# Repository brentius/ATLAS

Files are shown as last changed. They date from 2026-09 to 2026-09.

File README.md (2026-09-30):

# ATLAS
*Written in the prophetic perfect tense to give myself some motivation*

ATLAS (Atomic-scale Tunneling and Local Analysis Syste*) is a low-cost scanning tunneling microscope (STM) build inspired by Dimsmary's OpenSTM project (https://github.com/Dimsmary/OpenSTM), with the end goal to accurately image carbon atoms on the lattice of a sample of HOPG.

## File Structure

```
pcb/
code/
cad/
sim/
README.md
LICENSE-HARDWARE
LICENSE-SOFTWARE
.gitignore
```
## Licenses

Hardware design files in `pcb/` and `cad/`, including schematics, PCB layouts,
footprints, and mechanical designs, are licensed under the
[CERN Open Hardware Licence Version 2 – Strongly Reciprocal](LICENSE-HARDWARE)
(`CERN-OHL-S-2.0`). Hardware circuit netlists in `sim/` are covered by the same
license.

Software in `code/` and simulation scripts in `sim/` are licensed under the
[GNU General Public License Version 3](LICENSE-SOFTWARE) (`GPL-3.0-only`).

## How does ATLAS work?
ATLAS is a **scanning tunneling microscope** (STM). Essentially, you have a tip of some hard conductive material (Pt-Ir in this case) that is brought within nanometers of a sample, and very slowly moved along it. As the tip moves along the sample, electrons can tunnel from the atoms in the sample to the tip, which creates a miniscule current. What an STM does is take that current and through PCB wizardry amplify it into something readable, and from that construct a 3D image of the sample at the atomic scale.
# The project itself...
## A bit about this project
*For a more detailed log, refer to my blog at brentius.github.io/blog.*

I first started thinking of this project after my GCSEs in late June 2026, but I really didn't start work until September/October of that year. I'd been (very slowly) working my way through Griffths's *Introduction to Quantum Mechanics* the year before, and I thought it'd be a great idea to simply have fun and play around with quantum tunneling for a bit. I also wanted to do an actual *practical* project, because I absolutely adore PCB design - it's almost theraputic (triggers the same bits of my brain as those iPad games where you need to connect the dots without the lines crossing each other). But before I started any work, the project had to satisfy a few criteria:

1. Is it cool or not? Self explanatory, and I think I made the right choice.
2. Will it kill me? No matter how cool a project, there's not much use in doing it if I die in the process; I'd quite like to stay alive, thank you very much.
3. What can I learn from it? I've always been itching to try my hand at FPGAs, and this project was the perfect opportunity to do so.
4. How expensive will it be? At the end of the day, I don't have infinite funding; if I fry a PCB, or I break a Pt-Ir tip, it's coming out of my own pocket. Not ideal.

The only project that really satisfied all 4 criteria was building an STM, so I got to work on it. I was on vacation in Spain and Sweden during July, so there really wasn't much I could do except for starting to work on the PCBs. And my god, were these a pain.

ATLAS consists of 3 PCBs:
1. **TIA/preamp**. This uses an OPA828 DAC, along with a 100M resistor, to take in the *absolutely miniscule* current from electrons tunneling from the sample to the tip and amplify it by ~10e8 V/A, to get 15 volts running out of the back. This was actually one of the easier PCBs to design, mostly because of how few components there were. The main difficulty in designing the TIA board was physical routing - the current input trace had to be as short as possible and use as little copper as possible, and it also needed to be fenced off with the Great Wall of Vias (there's probably a Latin joke to be made in there but frankly I'm too dumb to make it) to protect it from interference from other traces. This meant that the shape of the board itself was hard to design, as the resistor meant that the board was quite large in both X and Y; considering this had to sit on the scanner block, it was not ideal.
2. **Converter/Pmod carrier**. This was about the point where I figured out I was probably extremely out of my depth. The Converter acts as a translator between the FPGA and the analog circuitry; onboard there's a SAR ADC, which takes the output from the TIA and digitises it for a PID loop. There are also two DAC8734s, that generate the X/Y/Z scan and feedback drive voltages (10 volts). Meanwhile, the AD7521 IC handles the DAC for the stick-slip sliding mechanism. Pmod headers carry SPI and control lines to and from the FPGA. As you can probably tell, this board was an absolute nightmare to design, and is the cause of many sleepless nights I will not get back.
3. **PSU**. All good things need power, and ATLAS is no exception. It runs on 15V - my original design called for a 45V rail to drive the tip movement for maximum range, but I decided against it for redundancy's sake - this project is already complicated enough without splitting 3 power rails (10, 15 and 45V).
### Damping
The PCBs were only one part of the challenge. A STM is an extremely sensitive instrument - after all, it's imaging individual atoms - even someone shouting next to it *will* throw the measurement off. To that end, ATLAS was built in one of the less used classrooms of Winchester College Mill, to keep foot traffic to a minimum; and a large sign was taped to the door telling people to keep their voices down. BUT THAT WASN'T ENOUGH! Any vibrations of the table would also throw the tip off by millimeters (matters a lot on the nanometer scale), so the whole system had to be on a damper.

The initial damper concept uses a frame, 8 springs and a 12lb slab of granite supporting the scanner assembly. The slab weight is adjustable rather than a fixed design requirement. No spring-rate or frequency measurement is recorded here, so the earlier 1Hz estimate is unverified. The [suspension calculation](sim/atlas_mechanics/SUSPENSION_BUDGET.md) and [comparison with other STM isolation designs](sim/atlas_mechanics/ISOLATION_OPTIONS.md) set out a modular trial of the spring stage, optional magnetic eddy-current damping and a short plate stack. Wind, sound and cable disturbances still need physical testing. I briefly considered building an enclosure with ANC, but I ultimately decided against it - the last thing I need is another signal processing challenge. It would be fun though...
## Assembly
*The instructions provided below are but a summary, and your version of ATLAS will probably not work if you just follow these. For a more detailed set of instructions, or if you'd like to see how I did it, please refer to brentius.github.io/blog.*

A full bill of materials can be found at ```BOM.md```.
### Part I. The Scanner Block
This is the scanner block - i.e. the block that actually does the scanning. One of the main insights I lifted from OpenSTM was to use a buzzer and a stick-slip mechanism to slowly increment the position of the tip, which franly I think was an insight of genius. Why a buzzer? While your typical linear actuators and belt drives work for 3D printing or CNC milling, an STM requires nanometer precision, which you physically can't achieve with a linear actuator. There's also the problem that linear actuators produce heat, which at nanometer scales, really throws the position off due to the joints expanding/contracting. We first quarter the 
#### Preparing the tip
Version 1 of ATLAS used a length of 80:20 Pt-Ir (platinum-iridium) wire that I simply cut at 45 degrees with a pair of sharp cutters. Boring, but it works.
# Meta Stuff
## Acknowledgements
# References

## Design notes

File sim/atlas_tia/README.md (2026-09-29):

# ATLAS TIA simulation

LTspice is suitable for the TIA compensation study. The `tia_opa828_*.cir`
files use TI's OPAx828 PSpice model. The `tia_proxy_*.cir` files are earlier
preliminary circuit checks using a deliberately simple 45 MHz gain-bandwidth
proxy. Open a `.cir` file in LTspice and click Run (or use LTspice batch mode).
For a `.cir` file, the working batch form is `LTspice.exe -b file.cir`.

## First TI-model run, 24 September 2026

LTspice 26.1.1 completed both TI-model netlists with exit code 0 and no logged
model errors. Baseline assumptions were 15 pF **external** input capacitance,
0.1 pF feedback stray capacitance, 100 pF output cable capacitance, and a
100 kΩ receiver. The 1 pA AC source gave about 99.8 MΩ low-frequency output
transimpedance. The 1 nA positive current step gave approximately -99.8 mV
output change (measured during the pulse, before it switched off).

| Fitted C1 | Simulated -3 dB bandwidth |
|---:|---:|
| 0.2 pF | 5.37 kHz |
| 0.5 pF | 2.66 kHz |
| 1 pF | 1.45 kHz |
| 5 pF | 0.312 kHz |

In this baseline, the maximum output magnitude from 1 Hz to 100 kHz occurred
at 1 Hz for all four values, so no gain peaking appeared in that interval.
The full 640-case parasitic/load and loop-gain sweep, tolerance corners,
step checks and evaluation are recorded in
[`COMPENSATION_STUDY.md`](COMPENSATION_STUDY.md).
The raw waveform and log files are local generated outputs and are ignored
by Git.

## Circuit represented

- 100 MΩ feedback resistor, stepped fitted C1 = 0.2, 0.5, 1, or 5 pF.
- Independent feedback stray capacitance, initially 0.1 pF.
- The proxy netlists add 15 pF for amplifier input capacitance. The TI-model
  netlists use the model's own input impedance and add only separately
  adjustable tip/PCB/cable capacitance.
- ±15 V incoming rails, 10 Ω series rail filters, 100 nF and 10 µF local
  capacitors on each rail.
- 220 Ω output resistor, provisional 100 kΩ receiver and output cable
  capacitance.

The AC files inject 1 pA AC into the tip. The transimpedance trace is
`-V(out)/1p`; nominal low-frequency magnitude is about 100 MΩ. Compare the
frequency response and peaking between C1 values. The step files apply
a 1 nA current step; the ideal settled output change is about -100 mV. The
proxy has only a single dominant pole and approximate output swing. It omits
the real amplifier's bias, noise, extra poles, overload behavior, and slew
limits. Consequently it cannot establish the planned 60° phase-margin gate.

## Remaining qualification

The 640-case AC and loop-gain sweeps are complete with the TI model. The
exact C1 part/tolerance, actual feedback stray capacitance, real cable and
receiver, supply impedance, noise, overload recovery and physical-board tests
remain open. The evaluation report states the population recommendation and
its limits.

The official TI archive `sbomaj0d.zip` and extracted `OPAx828.LIB` are in the
local `vendor/` directory, which is ignored by Git because the model is TI's
copyrighted evaluation material. The archive was downloaded from the OPA828
product page on 24 September 2026. Its top-level declaration is
`.SUBCKT OPAx828 IN+ IN- VCC VEE OUT`; the TI netlists connect `0 TIP VP VN RAW`
in that exact order. The model's usage notes list differential and common-mode
input impedance among the modeled parameters, so the TI netlists add only
external input capacitance. Model-specific results still require checking the
LTspice log and the physical board.

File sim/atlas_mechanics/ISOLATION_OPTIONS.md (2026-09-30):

# ATLAS isolation architecture comparison — 30 September 2026

## Recommendation for the next prototype

Use the existing spring-frame concept as a **modular test platform**, with
the total suspended mass adjustable. Compare (A) the bare suspended stage,
(B) the same stage with a conductive plate moving past frame-fixed magnets
for non-contact eddy-current damping, and (C) a short, two- or three-plate
metal/elastomer stack on the stage if the first two configurations leave
high-frequency coupling. This is a test sequence, **not** a selected slab
weight, spring, magnet gap or fabrication release. Keep the scanner, sample
and preamplifier on the same compact upper assembly; do not split the
tip/sample mechanical loop across stages. Fit, magnetic compatibility and
performance must be checked before adding a damper near the instrument.

Do not substitute passive permanent-magnet levitation for the springs at
this stage. The cited STM examples use magnets for **eddy-current damping**
of a mechanically supported mass, not as the vertical support. Static
permanent-magnet support of an ordinary ferromagnetic stage is not stable
in all directions without additional constraints or active control; a
levitation system would also introduce a new control/fault path. This is
an engineering recommendation based on the sources below, not a measured
comparison on ATLAS.

## Evidence from other STM builds

| Source and implementation | What it establishes | Limit for ATLAS |
|---|---|---|
| [OpenSTM build paper, section 5.1](https://arxiv.org/pdf/2310.05413) | Its reported build suspended a 10 kg stone from four springs, each listed at 408 N/m, and placed three 20 × 20 × 1 cm aluminium plates separated by fluoro-rubber rings on it. The paper says other isolation methods can be used. | It does not measure ATLAS's spring rate, mode frequencies or vibration transfer. Its four-spring value cannot be copied into an eight-spring design without recalculation. |
| [Dan Berard's build account](https://dberard.com/home-built-stm/vibration-isolation/) | Three long springs support an aluminium/MDF stage with a three-steel-plate Viton stack; fixed magnets near the moving aluminium plate provide eddy-current damping. The builder reports about 1 Hz **horizontal pendulum** and 2 Hz **vertical spring** resonances and uses fine 40 AWG wiring. | His 1 Hz number is not a vertical-spring specification and his site does not provide an ATLAS transfer measurement. |
| [J. Herkenhoff's STM repository](https://github.com/jherkenhoff/STM) | Uses steel plates separated by Viton pieces and describes optional spring/elastic-rope suspension and aluminium-base eddy-current damping. | Build description, not an ATLAS head/fixture qualification. |
| [Le's STM isolation thesis](https://digitalcommons.calpoly.edu/theses/2272/) | Develops a six-spring suspended copper stage with neodymium-magnet eddy-current damping and Viton at contacts. | Different geometry and environment; magnet position and damping remain to be engineered for ATLAS. |
| [Schmid and Varga, *Ultramicroscopy* (1992)](https://www.sciencedirect.com/science/article/pii/0304399192904934) | Their analysis finds spring/eddy-current and elastomer plate stages complementary. It also notes plate stacks can amplify some 10–100 Hz vibration and suggests only a few plates. | Do not add a plate stack on the assumption that more layers always improve isolation; compare transfer measurements. |
| [University of Virginia magnetic-levitation note](https://galileo.phys.virginia.edu/classes/317.gbh.fall05/mag-lev/mag-lev.html) | Explains why ordinary static permanent-magnet levitation is unstable without special materials or feedback. | Does not rule out every magnetic bearing, but does not justify a passive levitated ATLAS stage. |

The build accounts report their own configurations. They are not controlled
A/B measurements on one STM. In particular, OpenSTM's HOPG imaging is
evidence for its whole build, not proof that one isolation element alone
would outperform another element on ATLAS.

| ATLAS option | Main advantage | Main unresolved cost or failure mode | Trial role |
|---|---|---|---|
| Spring-supported mass alone | Reuses the present frame; mass and stiffness can be measured directly | Resonant amplification and cable bypass | Baseline first |
| Springs plus eddy-current plate/magnets | Adds adjustable non-contact damping without magnetic support | Magnetic interaction, extra moving mass and gap/clearance control | Reversible second configuration |
| Short metal/elastomer plate stack | Additional high-frequency attenuation may be possible | Creep, load/temperature dependence and possible 10–100 Hz amplification | Compare only if baseline/damper data justify it |
| Passive permanent-magnet levitation | Could remove a direct mechanical support path in a specialized design | Ordinary static magnets do not give stable unconstrained support; requires a different architecture | Not selected |
| Actively stabilized magnetic stage | Stability can be controlled in principle | Sensors, actuator power, control noise and fault behavior become part of the STM | Outside this prototype comparison |

## Mass and spring-rate implications

The [earlier suspension budget](SUSPENSION_BUDGET.md) correctly found that,
for **vertical, linear, zero-preload springs retuned to maintain exactly
1 Hz**, `mg/k = g/(2πf)² = 248 mm`, regardless of mass. The user's ability
to change slab mass matters when the **installed spring stiffness stays
fixed**: `f = sqrt(k/m)/(2π)` decreases and `mg/k` increases as mass is
added. Initial spring tension, angled mounts, geometric stiffness and
load-dependent rate invalidate the simple stretch interpretation; use the
loaded effective stiffness and measured free decay.

The following are **calculated illustrations**, assuming the OpenSTM
paper's 408 N/m rate for *each* spring, vertical equal load sharing, no
preload and no other moving mass. These are **not** ATLAS spring data.

| Example | Combined `k` | Moving mass | Ideal vertical `f` | `mg/k` |
|---|---:|---:|---:|---:|
| Four OpenSTM-rate springs, 12 lb slab | 1632 N/m | 5.443 kg | 2.76 Hz | 32.7 mm |
| Four OpenSTM-rate springs, 10 kg stone | 1632 N/m | 10.0 kg | 2.03 Hz | 60.1 mm |
| Eight OpenSTM-rate springs, 12 lb slab | 3264 N/m | 5.443 kg | 3.90 Hz | 16.4 mm |
| Eight OpenSTM-rate springs, 10 kg stone | 3264 N/m | 10.0 kg | 2.88 Hz | 30.0 mm |

At 3264 N/m, an eight-spring stage would need **20.67 kg total moving
mass** for an ideal 2 Hz vertical mode, before accounting for the head,
cables and elastomer compliance. That is not a recommended weight: frame
capacity, spring extension, handling and floor loading have not been
checked. Four 408 N/m springs with 10 kg alone yield 2.03 Hz; added
plates/head would lower that low-frequency estimate. Berard's reported
1 Hz horizontal pendulum and 2 Hz vertical mode are consistent with these
being distinct degrees of freedom, not interchangeable design targets.

Run `suspension_sizing.py` with the **measured total moving mass and
loaded effective spring rate** when available. Example (illustrative
OpenSTM-rate springs, not ATLAS measurements):

```text
python sim/atlas_mechanics/suspension_sizing.py --mass-kg 5.44310844 --spring-count 8 --spring-rate-n-m 408 --target-hz 2
```

The tool reports the frequency, `mg/k` and mass needed for the requested
target at fixed stiffness. It cannot choose a safe slab or predict damping.

## Reversible comparison and acceptance gate

1. Record actual frame geometry, support capacity, spring count, loaded
   tangent stiffness, clearance and total moving mass. Check all mounts,
   cables and possible bottoming before adding mass. Obtain vertical,
   lateral, pitch and roll free-decay records with the intended cable loom.
2. Establish a baseline with the existing slab and spring arrangement.
   Record simultaneous frame and stage motion during a quiet interval and
   a repeatable small excitation, with a dummy head in place of a live
   tip/sample. Resolve the vertical mode and transfer over at least
   0.5–100 Hz if the sensors permit; retain the raw traces, sensor
   calibration, locations, added sensor mass, sample rate and uncertainty.
   Repeat each configuration at least three times.
3. If resonance ring-down is excessive, test a detachable conductor plate
   on the moving stage and magnets fixed to the frame. Change only the
   magnet gap between runs. Compare magnets near/far at the same moving
   mass and cable routing; use nonmagnetic dummy ballast if removing the
   conductor otherwise changes mass. Keep mechanical clearance and check
   whether fields affect scanner magnets, approach mechanics or
   electronics. A magnet is not an acceptable mechanical stop or
   structural support.
4. If high-frequency transfer remains problematic, compare a two- or
   three-plate elastomer stack using the same head position and cables.
   Record pad geometry, compression, temperature and creep. Look for
   amplification in the 10–100 Hz band as well as attenuation.
5. Select the lowest-complexity configuration that measurably reduces
   tip–sample disturbance without unacceptable resonance, drift, cable
   coupling, clearance or approach-motion penalties. Repeat scans or
   tunnelling-current noise checks only after the mechanical comparison
   and electrical baseline exist. The pass criterion is a reproducible
   reduction in stage/frame transfer or junction-noise spectrum under
   matched conditions, with no new amplified band or clearance failure;
   numerical limits require the measured site and head noise budget.
   No imaging result is claimed here.

The next physical input is the **actual loaded spring rate and complete
moving mass**. Without those two values, changing slab weight is a tuning
experiment rather than a justified design selection.

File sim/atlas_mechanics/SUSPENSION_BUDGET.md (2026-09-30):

# ATLAS suspension frequency check — 30 September 2026

## Finding

The [README](../../README.md#damping) describes an eight-spring suspension
carrying a 12 lb granite slab and states a 1 Hz natural frequency. No spring
rate, total moving mass, geometry, damping measurement or free-decay record
is available in this repository. **The 1 Hz value is unverified here.**
This calculation does not select a spring or change the head design. The
[isolation-options review](ISOLATION_OPTIONS.md) compares other STM builds
and shows how adjustable slab mass changes frequency at fixed spring rate.

For an ideal vertical, linear, zero-preload spring set carrying only the
stated slab mass, a 1 Hz vertical mode requires **215 N/m combined tangent
stiffness**, or **26.9 N/m per spring** if eight springs share the load
equally. The corresponding static stretch from the unloaded length is
**248 mm**. A suspension with initial tension, preload, angled springs or
nonlinear stiffness can have a different unloaded-to-loaded stretch; its
frequency must be established from the loaded tangent stiffness or measured
motion. The clearance and available extension of the actual frame are not
documented.

## Inputs and equations

| Quantity | Value | Origin |
|---|---:|---|
| Granite slab | 12 lb = 5.4431 kg | README claim; mass not independently weighed |
| Spring count | 8 | README claim; geometry and load sharing unknown |
| Gravity | 9.80665 m/s² | Calculation convention |
| Target vertical frequency | 1 Hz | README claim; not a measured result in this repository |

For a single vertical degree of freedom with total moving mass `m` and
effective vertical tangent stiffness `k`, `f_n = sqrt(k/m)/(2π)`. Thus
`k = m(2πf_n)²`. For eight equal vertical springs in parallel,
`k_each = k/8`. If they are linear and have no preload, force balance gives
`Δ = mg/k = g/(2πf_n)²`. This idealized `Δ` is independent of mass at a
fixed target frequency, but required spring stiffness rises with mass.

| Target `f_n` | Total `k` for 5.4431 kg | Equal-spring `k_each` | Zero-preload static stretch |
|---:|---:|---:|---:|
| 1 Hz | 214.9 N/m | 26.9 N/m | 248.4 mm |
| 1.5 Hz | 483.5 N/m | 60.4 N/m | 110.4 mm |
| 2 Hz | 859.5 N/m | 107.4 N/m | 62.1 mm |
| 3 Hz | 1934.0 N/m | 241.7 N/m | 27.6 mm |

At 1 Hz with the slab alone, each equally loaded spring carries 6.67 N.
If the actual suspended head, fixtures and cables add 1.0 kg while the
combined stiffness stays 214.9 N/m, the ideal vertical frequency falls to
0.919 Hz. This is a sensitivity example, not an estimate of the head mass.
For an angled axial spring, its small-motion vertical contribution is
approximately `k_axial cos²θ`; load sharing and geometric stiffness need
the actual mounting coordinates and tension. Flexible cables may add both
stiffness and a direct disturbance path.

Isolation is frequency-dependent. In a simple base-excited, single-mode
model, displacement transmissibility is
`T = sqrt(1 + (2ζr)²) / sqrt((1-r²)² + (2ζr)²)`, where `r` is forcing
frequency divided by natural frequency and `ζ` is damping ratio. For an
*illustrative*, unmeasured `ζ = 0.10`, this model gives `T = 5.10` at
resonance, `0.356` at twice the natural frequency and `0.0589` at five
times it. A 1 Hz mode therefore does not imply immunity to wind, sound,
direct cable force, or excitation near 1 Hz. Damping, lateral/tilt modes
and acoustic coupling have not been measured.

## Physical check before treating 1 Hz as a design result

1. Weigh the entire moving assembly with its actual cables in place.
   Record slab, head, fixtures and any attached cable mass separately.
2. Record unloaded and loaded spring lengths, mount angles, vertical travel
   and minimum clearance to the frame. Check for coil bind and contact at
   both static position and expected motion extremes.
3. With the assembly safely restrained, add and remove a known small mass
   near its centre and measure the incremental vertical displacement. In a
   locally linear suspension, `k_eff = Δm g / Δx`. At the calculated 1 Hz
   slab-only stiffness, a 0.5 kg increment would move it about 22.8 mm;
   this is a predicted diagnostic scale, not a load instruction for an
   unverified frame. Repeat at several loads to reveal nonlinearity and
   unequal spring sharing.
4. Record at least three small-amplitude free decays of the fully assembled
   suspension. From successive peak times obtain the vertical period and
   frequency; from peak ratios estimate damping. Repeat with cables in
   their intended restrained configuration. Check lateral, pitch and roll
   modes separately, as one vertical number cannot qualify the head.
5. Record the measurement method, sensor calibration, load and cable state,
   amplitudes, uncertainty and raw time series. Compare the measured modes
   with disturbances at the bench and with the head's own mounted modes.

Do not use this model alone to release the suspension or assert imaging
stability. It only identifies the stiffness and travel scale that the
stated 1 Hz claim would require under explicit assumptions.

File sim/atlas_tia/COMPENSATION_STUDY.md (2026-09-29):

# ATLAS TIA compensation simulation — 24 September 2026

## Decision

The nominal 0.2 pF and 0.5 pF C1 populations both satisfy the planned
**≥1 kHz bandwidth, ≥60° phase margin, and ≤1 dB peaking** limits in all
160 declared capacitance/load combinations for each value. **0.5 pF has only
61 Hz of minimum-bandwidth margin.** An illustrative +0.1 pF fitted-capacitor
shift makes its worst corner miss 1 kHz, especially with R1 at +1%. The
0.2 pF population retains at least 212 Hz margin at the corresponding
illustrative +0.1 pF, +1% R1 corner. Prefer **0.2 pF for the first prototype
population**, with 0.5 pF assembled as a comparison if practical. Final C1
selection requires physical bandwidth/noise tests. The KiCad first-prototype
population is now YAGEO `CQ0603BRNPO9BNR20` (0.2 pF, ±0.1 pF, 50 V,
C0G/NP0, 0603). The 0.5 pF option remains a comparison population.

## Model and circuit

- LTspice 26.1.1, TI `OPAx828.LIB` model Final 1.3 from `SBOMAJ0D.ZIP`.
  Top-level model order: `IN+ IN- VCC VEE OUT`. The model includes input
  impedance, so only external capacitance is added at `TIP`.
- KiCad design values: OPA828, R1=100 MΩ, R2=220 Ω, ±15 V feeds each through
  10 Ω, 100 nF and nominal 10 µF local rail capacitors. The output load is
  after R2.
- Additional input capacitance: 0, 5, 15, 35, 85 pF. Feedback stray
  capacitance: 0, 0.1, 0.3, 1 pF. Cable capacitance after R2: 0, 100, 500,
  1000 pF. Receiver: 100 kΩ or approximately open (1 TΩ). Fitted C1: 0.2,
  0.5, 1, 5 pF. This is 640 cases in each AC and loop-gain run.
- AC bandwidth is the first -3 dB crossing relative to the 1 Hz output
  magnitude for a 1 pA input current. Peaking is the maximum magnitude from
  1 Hz to 10 MHz relative to that 1 Hz value. Loop margin uses a 0 V DC / 1 V
  AC series source between the amplifier output and feedback branch;
  return ratio is `-V(AMP)/V(FB)`, with other AC inputs zero. Phase margin
  is 180° plus return-ratio phase at its 0 dB crossing. All cases had one
  bandwidth crossing and one loop-gain unity crossing.

## Full matrix results

| Fitted C1 | Cases meeting all three limits | -3 dB bandwidth range | Phase-margin range | Maximum peaking |
|---:|---:|---:|---:|---:|
| 0.2 pF | 160/160 | 1.327–8.716 kHz | 84.5–89.5° | 0.00 dB |
| 0.5 pF | 160/160 | 1.061–3.228 kHz | 86.2–89.5° | 0.00 dB |
| 1 pF | 120/160 | 0.796–1.597 kHz | 85.4–89.5° | 0.00 dB |
| 5 pF | 0/160 | 0.265–0.318 kHz | 81.2–88.7° | 0.00 dB |

The minimum bandwidth for each fitted value occurred with 0 pF additional
input, 1 pF feedback stray, 1000 pF cable and a 100 kΩ receiver. Failure
of the 1 pF and 5 pF options is due to bandwidth, not simulated phase margin
or peaking. The full per-case results are in
[`results/compensation_sweep.csv`](results/compensation_sweep.csv).

## Tolerance and transient checks

The selected [YAGEO Hi-Q NP0 series datasheet](https://yageogroup.com/content/datasheet/asset/file/UPY-HIGH_Q_NP0_16V-TO-500V)
defines the `B` tolerance code as ±0.1 pF, and the
[part listing](https://www.digikey.in/en/products/detail/yageo/CQ0603BRNPO9BNR20/11497278)
confirms the selected 0603 part's 0.2 pF, 50 V and C0G ratings. The
±0.1 pF corners below therefore match its stated tolerance, but remain
illustrative for the assembled circuit because actual pad and trace
capacitance are unmeasured. At the minimum-bandwidth load above:

| Nominal C1 and tolerance corner | R1 | Bandwidth | Phase margin |
|---|---:|---:|---:|
| 0.2 pF nominal, C1=0.3 pF | 101 MΩ | 1.213 kHz | 87.3° |
| 0.5 pF nominal, C1=0.6 pF | 100 MΩ | 0.995 kHz | 87.0° |
| 0.5 pF nominal, C1=0.6 pF | 101 MΩ | 0.985 kHz | 87.0° |

At the high-input-capacitance phase corner (85 pF extra input, 0 pF feedback
stray, 1000 pF cable, open receiver), C1=0.1 pF with R1=99–101 MΩ gave
71.2–71.5° phase margin. This tests the low side of an illustrative
selected 0.2 ±0.1 pF C1 population.

Four 1 nA step checks covered the minimum-bandwidth and minimum-phase-margin
corners for 0.2 and 0.5 pF. The measured change at 0.9–1.0 ms was -99.43
to -100.00 mV; no undershoot beyond the value at 1.099 ms was detected.
The last 100 µs before that point varied by at most 0.235 mV, consistent
with continuing settling at the slow corners. See
[`results/transient_corners.csv`](results/transient_corners.csv).

Replacing each nominal 10 µF local bulk capacitor with 1 or 3 µF changed
the minimum-bandwidth results by less than the printed 0.001 Hz and phase
margin by about 0.001° in this ideal-source model. This **does not**
validate supply decoupling against actual PSU/cable impedance or rail noise.

## Limits before PCB release

### Feedback stray headroom update — 29 September 2026

A targeted high-side tolerance study (C1 = 0.3 pF, R1 = 101 MΩ) found the
modeled 1 kHz bandwidth crossing at about 1.276 pF additional feedback
capacitance, or 1.576 pF fitted-plus-stray. The prior 1 pF stray envelope
therefore has about 0.276 pF of model headroom at that tolerance corner. An
80-case input/output-load check gave 40/40 passing at 1.27 pF stray and 0/40
passing at 1.28 pF. The reproducible decks, derived results and physical
test recommendation are in
[`FEEDBACK_STRAY_BUDGET.md`](FEEDBACK_STRAY_BUDGET.md).
This diagnostic estimate does not change C1 population or qualify the
assembled PCB. Measure the board's actual bandwidth with its harness and
receiver before release.

- The TI macromodel and ideal parasitic elements do not predict PCB leakage,
  contamination, the actual 0603 pad/guard capacitance, feedback-resistor
  excess noise, or mechanically induced current. The 1 pF feedback-stray
  value is an assumed envelope, not a measurement of the routed board.
- C1's first-prototype part and absolute tolerance are now recorded in
  KiCad. Confirm procurement and assembly availability before ordering;
  the 0.5 pF comparison part remains to be selected. Verify the assembled
  board's effective feedback capacitance and bandwidth.
- Receiver impedance and cable capacitance are provisional until the
  converter and harness are designed. Rail filtering needs a realistic
  source-impedance/noise model and bench measurement.
- Bench qualification still needs bipolar current injection, bandwidth,
  noise spectra, leakage, overload recovery, cable-load response and warm-up
  drift. Simulated phase margin does not replace these checks.

Reproduce the sweep with `LTspice.exe -b tia_opa828_ac_sweep.cir` and
`LTspice.exe -b tia_opa828_loop_sweep.cir` from `sim/atlas_tia`
directory, then run
`summarize_sweep.py` against the two base paths. The raw and log outputs are
ignored by Git; the result CSV is retained.

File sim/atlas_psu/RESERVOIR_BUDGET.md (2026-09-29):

# PSU reservoir and transformer envelope — 29 September 2026

## Provisional circuit update

C1/C2 in the PSU schematic now use **4700 µF, 50 V** Nichicon
`LGY1H472MELB30`, matching the exact part and 30 mm / 10 mm snap-in
footprints already on the PSU PCB. The [Nichicon LGY series datasheet](https://www.nichicon.com/getmedia/6716b3c6-abcc-4da1-80b0-b33e29e5a195/e-lgy-DB.pdf)
lists this part as 30 × 30 mm, ±20%, with 2.1 A RMS rated ripple at
105°C/120 Hz. Its 50–120 Hz frequency coefficient is 0.88–1.00. Check
assembly sourcing and the actual capacitor current waveform before release.

This restores schematic/PCB part parity and improves the calculated
low-line trough. In the simplified case below, 4700 µF leaves +2.49 V
idealized headroom at 216.2 V input, or +0.70 V at 200 V input, during
the hypothetical additional 0.5 A / 10 ms pulse. The 200 V margin is
small before winding, ESR and wiring losses. **The circuit is a
prototype population, not a validated PSU rating.** Larger capacitance
raises stored energy, inrush and discharge time: each nominal 4700 µF
reservoir holds about 2.56 J at 33 V and takes about 89 s to fall from
33 V to 5 V through a 10 kΩ bleeder alone (about 112 s at +20% C and
+5% R). The enclosure and bench procedure must treat the rails as live
until measured discharged.

## Finding

An earlier PSU schematic candidate used **2200 µF, 50 V** Ymin
`LKMJ2501H222MF` for both raw reservoirs, while the board still carried
4700 µF Nichicon parts. The analysis below preserves that comparison and
uses the existing plan assumptions; it does not qualify either population.

The former 2200 µF low-line example has about **2.80 V** of idealized raw-rail
headroom beyond a 15.1 V output plus a provisional 3.0 V regulator
differential. A hypothetical **additional 0.5 A for 10 ms** consumes
`0.5 A × 10 ms / 1760 µF = 2.84 V` at the capacitor's -20% tolerance;
the calculated headroom becomes **-0.04 V** even before winding, wiring,
ESR and regulator transient losses. The earlier plan's 2.3 V pulse estimate
used the nominal 2200 µF rather than the minimum 1760 µF. This pulse is an
illustrative stack demand, not a measured load or fixed requirement.

The candidate Vigortronix `VTX-146-030-218` specifies a **200–264 V**
series-primary input range, 2 × 18 V, 0.83 A, 30 VA and **14% typical**
regulation in its [manufacturer datasheet](https://www.vigortronix.com/wp-content/uploads/2021/09/VTX-146-xxxx-2-Series-Dual-Primary-Toroida-D0008.pdf).
The plan's 216.2 V (-6%) case is therefore only one possible low-line
scenario. At the datasheet's 200 V input limit, the same idealized estimate
has only **1.00 V** headroom without a pulse and **-1.84 V** with the pulse.
Whether ATLAS must operate throughout 200–264 V is a project requirement
decision; this review does not silently extend it.

| Primary input | Capacitor | No-pulse headroom | Headroom with +0.5 A for 10 ms |
|---:|---:|---:|---:|
| 216.2 V | 2200 µF | +2.80 V | -0.04 V |
| 216.2 V | 3300 µF | +3.44 V | +1.55 V |
| 216.2 V | 4700 µF | +3.82 V | +2.49 V |
| 200.0 V | 2200 µF | +1.00 V | -1.84 V |
| 200.0 V | 3300 µF | +1.65 V | -0.25 V |
| 200.0 V | 4700 µF | +2.03 V | +0.70 V |

The 4700 µF row is the selected provisional prototype population; 2200
and 3300 µF are comparisons. Larger capacitance also affects inrush,
charging-current RMS, bleeder time, package/footprint and cost. The table
cannot establish a release rating until the stack current waveform and
required primary-voltage range are established.

## Reproducible method and limits

`reservoir_budget.py` writes the full derived table to
`results/reservoir_budget.csv`. It uses:

`Vpeak = 18 Vrms × (Vprimary / 230 V) × √2 − 1.1 V`

`Vtrough = Vpeak − (0.34 A × 10 ms + Ipulse × 10 ms) / (0.8 × Cnominal)`

`headroom = Vtrough − 15.1 V − 3.0 V`

The 18 Vrms at 230 V and 0.34 A positive-rail average draw come from the
local PSU plan; 1.1 V one-diode drop and 3.0 V regulator differential are
its provisional assumptions. Both the selected
[Nichicon LGY](https://www.nichicon.com/getmedia/6716b3c6-abcc-4da1-80b0-b33e29e5a195/e-lgy-DB.pdf)
and former [Ymin LKM](https://www.ymin.cn/lead-type-miniature-type-aluminum-electrolytic-capacitor-lkm-product/)
series list **±20%** capacitance tolerance at 120 Hz.
The 10 ms no-recharge interval is a simple upper-bound discharge model at
100 Hz. It does not account for capacitor-input transformer loading, winding
resistance/regulation under pulsed charge, rectifier conduction angle,
capacitor ESR, capacitance versus temperature/frequency/age, wiring drop,
regulator current limits, recovery, or regenerated stack energy. The actual
raw trough can differ in either direction; this estimate is insufficient
for release.

## Ripple-current correction and high-line ceiling

The [Ymin LKM page](https://www.ymin.cn/lead-type-miniature-type-aluminum-electrolytic-capacitor-lkm-product/)
lists this part at 3.57 A RMS rated ripple current and gives frequency
coefficients of **0.4 at 50 Hz, 0.5 at 120 Hz and 1 at 100 kHz**. Thus the
plan's provisional `0.65 × 3.57 ≈ 2.3 A at 100 Hz` is not supported by the
manufacturer's coefficients. Direct multiplication gives 1.43 A at 50 Hz
and 1.79 A at 120 Hz at the table's reference temperature. The actual
capacitor charging waveform contains harmonics, so its heating must be
checked using measured/simulated current RMS and spectral content, not a
single 100 Hz multiplier. No capacitor ripple-current margin is claimed.

At the datasheet's 264 V upper input and **typical** 14% no-load regulation,
the ideal secondary peak before rectifier drop is
`18 × (264/230) × 1.14 × √2 = 33.31 V`. At light load the diode drop can be
small, so the plan's provisional **33 V raw ceiling** is not a guaranteed
upper bound over the transformer's full input range. The 14% is typical,
not a guaranteed maximum. Device-voltage, reservoir-energy and thermal
checks need a justified system high-line limit and transformer tolerance.

## Required discriminator

Define the maximum *additional* stack pulse current, duration, repetition
rate and which rail it loads; define ATLAS's intended AC input range.
Then model the exact transformer with measured or guaranteed winding
impedance, rectifier and capacitor ESR, and test the built supply under
combined/asymmetric loads. Record both raw troughs, regulator outputs,
capacitor current RMS, rail-valid behavior and temperature. Retain 2200 µF
as an alternative only if the measured/revised model margins and thermal
limits meet the agreed operating envelope. No mains wiring was changed.

## KiCad verification

KiCad 10.0.6 ERC on the revised schematic found **no errors** and one
warning for the intentionally isolated `CHASSIS` contact. DRC with
schematic parity found **zero parity issues** after matching C1/C2 fields
between schematic and board. The unfinished PSU PCB still reports
**106 design-rule violations**, **118 unconnected items** and no valid
`Edge.Cuts` outline. Generated JSON reports are kept locally under the
ignored `pcb/atlas_psu/routing_review/` directory. These results verify
part-field consistency, not layout or electrical readiness.

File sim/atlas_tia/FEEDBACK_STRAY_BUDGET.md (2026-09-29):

# TIA feedback-capacitance budget — 29 September 2026

## Result and interpretation

**Simulated, not measured.** With the selected C1 at its stated high tolerance
end (0.3 pF), R1 at the schematic's assumed +1% end (101 MΩ), and the
existing TI OPAx828 macromodel, the 1 kHz closed-loop bandwidth boundary is
approximately **1.276 pF of additional feedback capacitance**. That is
approximately 1.576 pF total fitted-plus-stray feedback capacitance. The
previous 1 pF stray assumption leaves about 0.276 pF of model headroom. No
assembled-board stray capacitance has been measured.

| Additional feedback C | Worst -3 dB bandwidth | Cases ≥1 kHz |
|---:|---:|---:|
| 1.00 pF | 1212.481 Hz | targeted load only |
| 1.20 pF | 1050.752 Hz | targeted load only |
| 1.27 pF | 1003.881 Hz | 40/40 |
| 1.28 pF | 997.530 Hz | 0/40 |
| 1.30 pF | 985.039 Hz | targeted load only |

The 40 cases at each bracket value cover 0/5/15/35/85 pF external input
capacitance, 0/100/500/1000 pF output cable capacitance, and 100 kΩ/1 TΩ
receivers. The minimum occurred at 0 pF added input, 1000 pF cable, and
100 kΩ receiver, as in the earlier sweep. All 80 cases had one -3 dB
crossing and 0 dB reported peaking over the simulated frequency range.

The interpolated 1.276 pF crossing is a **diagnostic model estimate**, not a
manufacturing tolerance or physical pass criterion. In particular, the
macromodel, ideal parasitic capacitors, unknown cover/lead geometry, and
unverified receiver prevent sub-0.01 pF predictions for a real board. The
simple RC estimate, `1/(2π × 101 MΩ × 1 kHz) = 1.57579 pF` total feedback
capacitance, independently agrees with the simulated 1.576 pF threshold but
cannot establish phase margin, peaking or noise. The prior sweep remains the
evidence for those other simulated limits inside its declared 0–1 pF stray
envelope.

## Physical acceptance check

For the assembled preamp, inject a calibrated small-signal current through a
known injection capacitor or other characterized current source without
permanently loading the tip node. Record its amplitude and uncertainty versus
frequency. With the intended harness and receiver connected, measure the
output transimpedance at a low reference frequency and the first -3 dB
crossing. Also repeat with the declared worst-case 1000 pF cable and 100 kΩ
receiver if that envelope remains the project requirement. The existing
≥1 kHz bandwidth and ≤1 dB peaking criteria apply to the **measured**
response. Record C1 population, R1 measurement, harness, receiver, source
calibration, and test conditions. The effective feedback capacitance may be
estimated from the response for diagnosis, but the measured frequency
response determines acceptance. Noise, leakage and overload recovery remain
separate checks.

## Reproduction and provenance

- Design inputs: `pcb/atlas_tia/atlas_tia.kicad_sch` records C1 = 0.2 pF,
  ±0.1 pF, and R1 = 100 MΩ, 1%; `tia_opa828_stray_budget_*.cir` record the
  analyzed high-side values and all loads.
- Model: local TI `OPAx828.LIB` Final 1.3 from `SBOMAJ0D.ZIP`, used by
  LTspice 26.1.1. Its licensed copy is deliberately excluded from Git.
- Run `LTspice.exe -b tia_opa828_stray_budget_ac.cir` and
  `LTspice.exe -b tia_opa828_stray_budget_envelope.cir` from `sim/atlas_tia`.
  Wait for `Total elapsed time:` in each log, then run
  `python summarize_stray_budget.py`. The derived 80-case table is
  `results/feedback_stray_budget.csv`; original local waveform/log files
  remain untouched and ignored by Git.
- The summary script checks step counts, unique crossings, the 1 kHz
  bracket, and agreement between the targeted and envelope runs.

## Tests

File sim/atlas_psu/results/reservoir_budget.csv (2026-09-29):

primary_v | nominal_cap_uf | minimum_cap_uf | extra_pulse_a | pulse_ms | ideal_peak_v | base_drop_v | pulse_drop_v | raw_trough_v | headroom_after_3v_allowance_v
216.2 | 2200 | 1759.9999999999998 | 0.0 | 0 | 22.828493475352765 | 1.931818181818182 | 0.0 | 20.89667529353458 | 2.796675293534582
216.2 | 2200 | 1759.9999999999998 | 0.5 | 10.0 | 22.828493475352765 | 1.931818181818182 | 2.8409090909090913 | 18.05576620262549 | -0.044233797374507944
216.2 | 3300 | 2640.0 | 0.0 | 0 | 22.828493475352765 | 1.287878787878788 | 0.0 | 21.540614687473976 | 3.4406146874739765
216.2 | 3300 | 2640.0 | 0.5 | 10.0 | 22.828493475352765 | 1.287878787878788 | 1.893939393939394 | 19.64667529353458 | 1.546675293534582
216.2 | 4700 | 3760.0000000000005 | 0.0 | 0 | 22.828493475352765 | 0.9042553191489362 | 0.0 | 21.924238156203828 | 3.824238156203828
216.2 | 4700 | 3760.0000000000005 | 0.5 | 10.0 | 22.828493475352765 | 0.9042553191489362 | 1.3297872340425532 | 20.594450922161275 | 2.494450922161276
200.0 | 2200 | 1759.9999999999998 | 0.0 | 0 | 21.035516628448445 | 1.931818181818182 | 0.0 | 19.10369844663026 | 1.0036984466302616
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

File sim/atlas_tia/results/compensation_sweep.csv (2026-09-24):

step | cfit_pf | cextra_pf | cstray_pf | ccable_pf | rreceiver_ohm | transimpedance_ohm | bandwidth_hz | peaking_db | unity_hz | phase_margin_deg | bandwidth_crossings | unity_crossings | passes
1 | 0.2 | 0.0 | 0.0 | 0.0 | 100000.0 | 99780482.4940571 | 8063.719008946155 | 0.0 | 595313.5489341987 | 88.87977497931439 | 1 | 1 | True
2 | 0.5 | 0.0 | 0.0 | 0.0 | 100000.0 | 99780478.3583644 | 3189.717979668554 | 0.0 | 1459199.1264113248 | 89.00813407747546 | 1 | 1 | True
3 | 1.0 | 0.0 | 0.0 | 0.0 | 100000.0 | 99780463.58719526 | 1592.353122328614 | 0.0 | 2826491.3989416827 | 88.28921745827091 | 1 | 1 | True
4 | 5.0 | 0.0 | 0.0 | 0.0 | 100000.0 | 99779990.89556184 | 318.3110785407027 | 0.0 | 11259099.883481136 | 83.28593441994752 | 1 | 1 | False
5 | 0.2 | 5.0 | 0.0 | 0.0 | 100000.0 | 99780482.50097036 | 8099.839599613633 | 0.0 | 447989.49222019897 | 88.71241444326444 | 1 | 1 | True
6 | 0.5 | 5.0 | 0.0 | 0.0 | 100000.0 | 99780478.36527172 | 3191.9606636745407 | 0.0 | 1103316.2458550767 | 89.17758794515578 | 1 | 1 | True
7 | 1.0 | 5.0 | 0.0 | 0.0 | 100000.0 | 99780463.59409282 | 1592.631471725365 | 0.0 | 2153750.406274025 | 88.6777859598464 | 1 | 1 | True
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

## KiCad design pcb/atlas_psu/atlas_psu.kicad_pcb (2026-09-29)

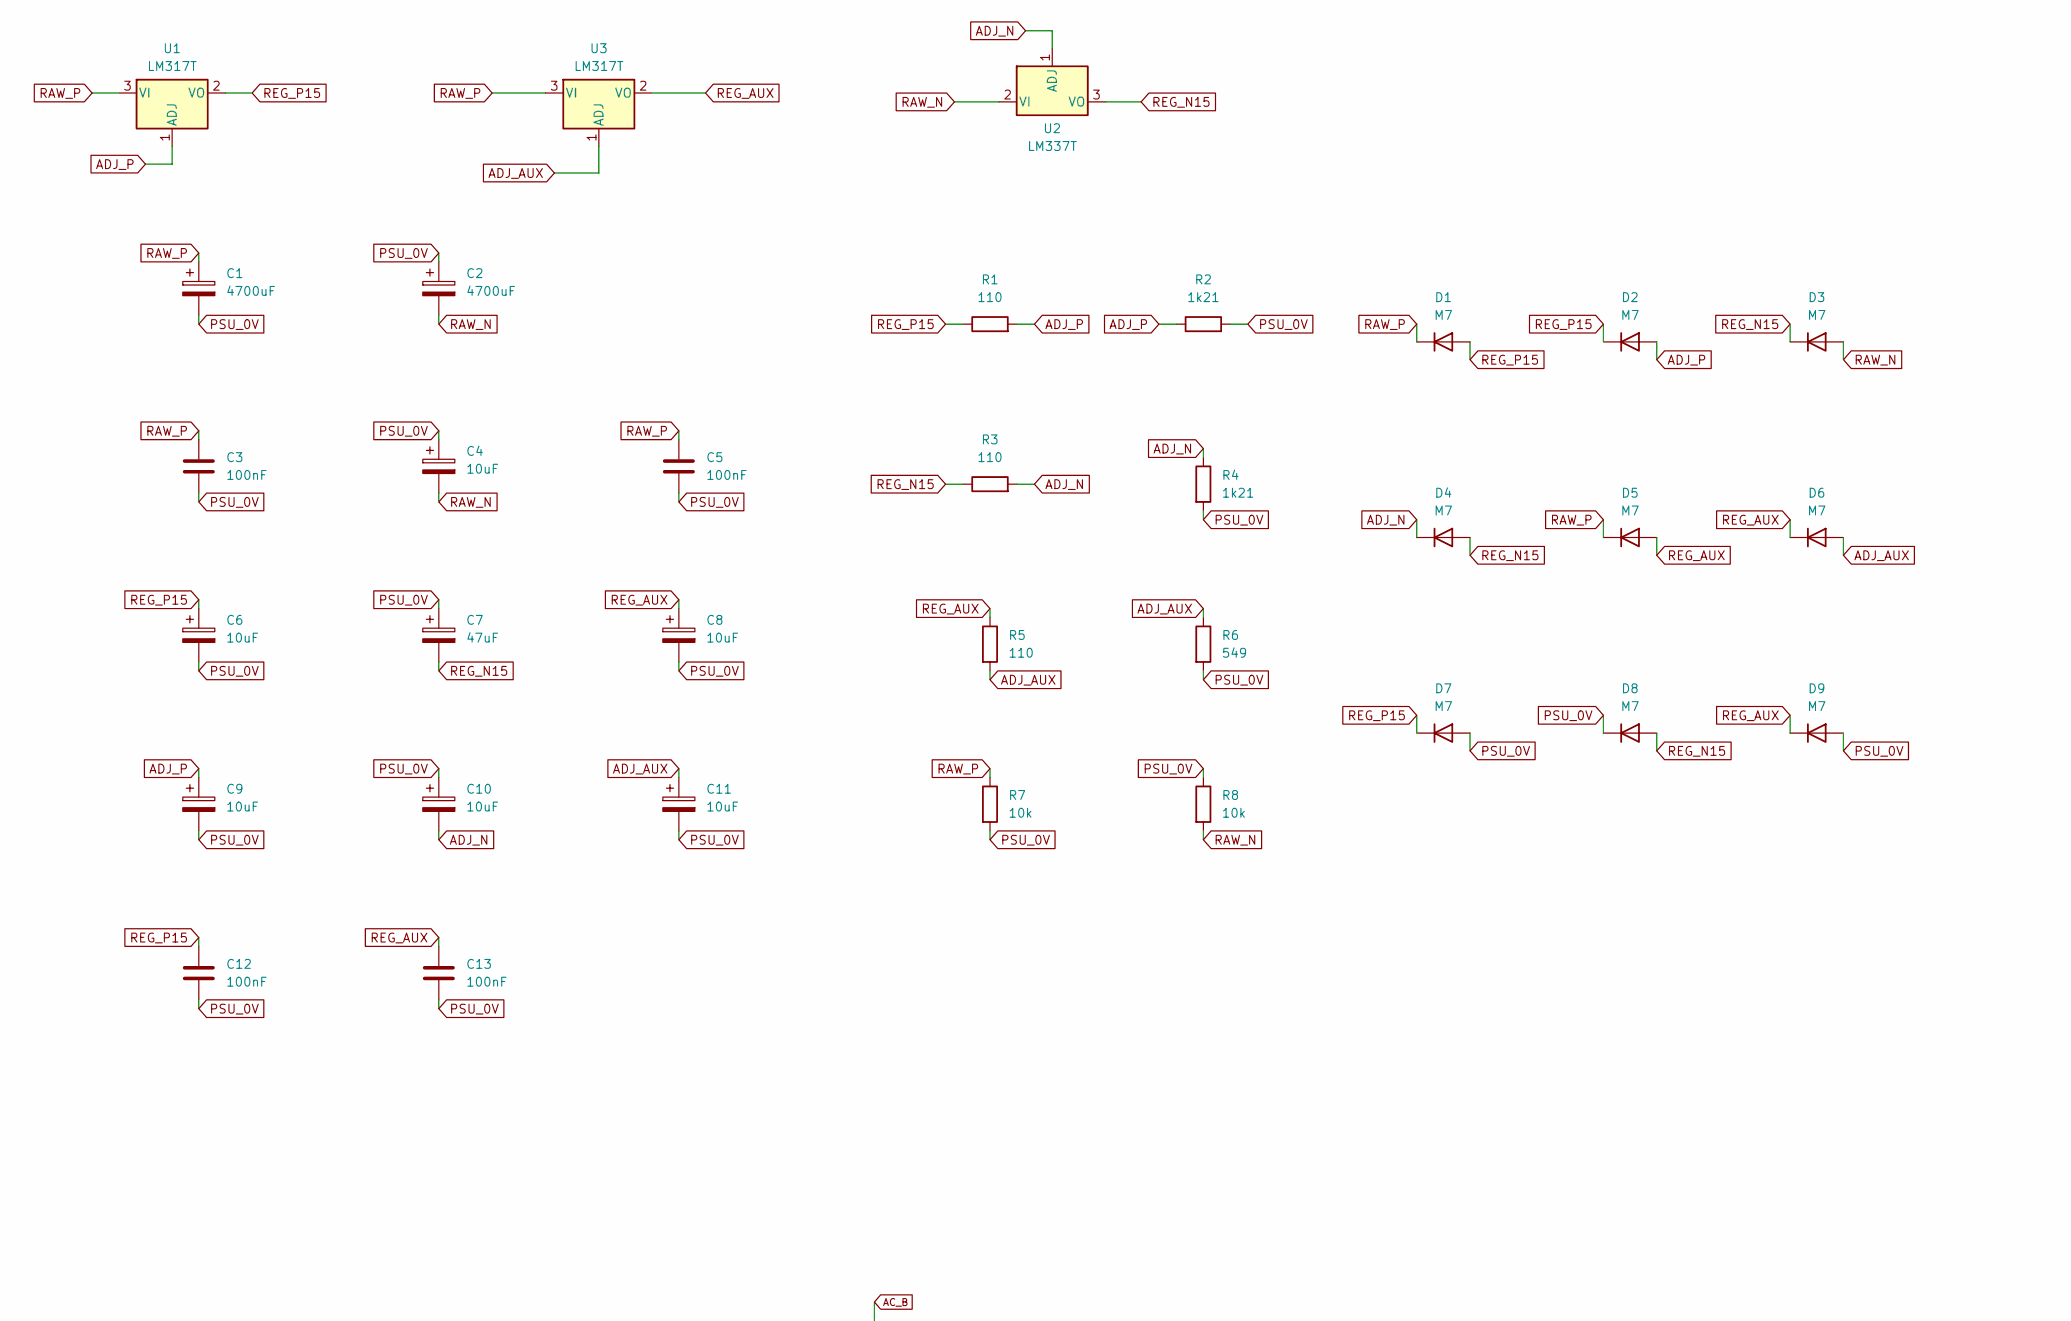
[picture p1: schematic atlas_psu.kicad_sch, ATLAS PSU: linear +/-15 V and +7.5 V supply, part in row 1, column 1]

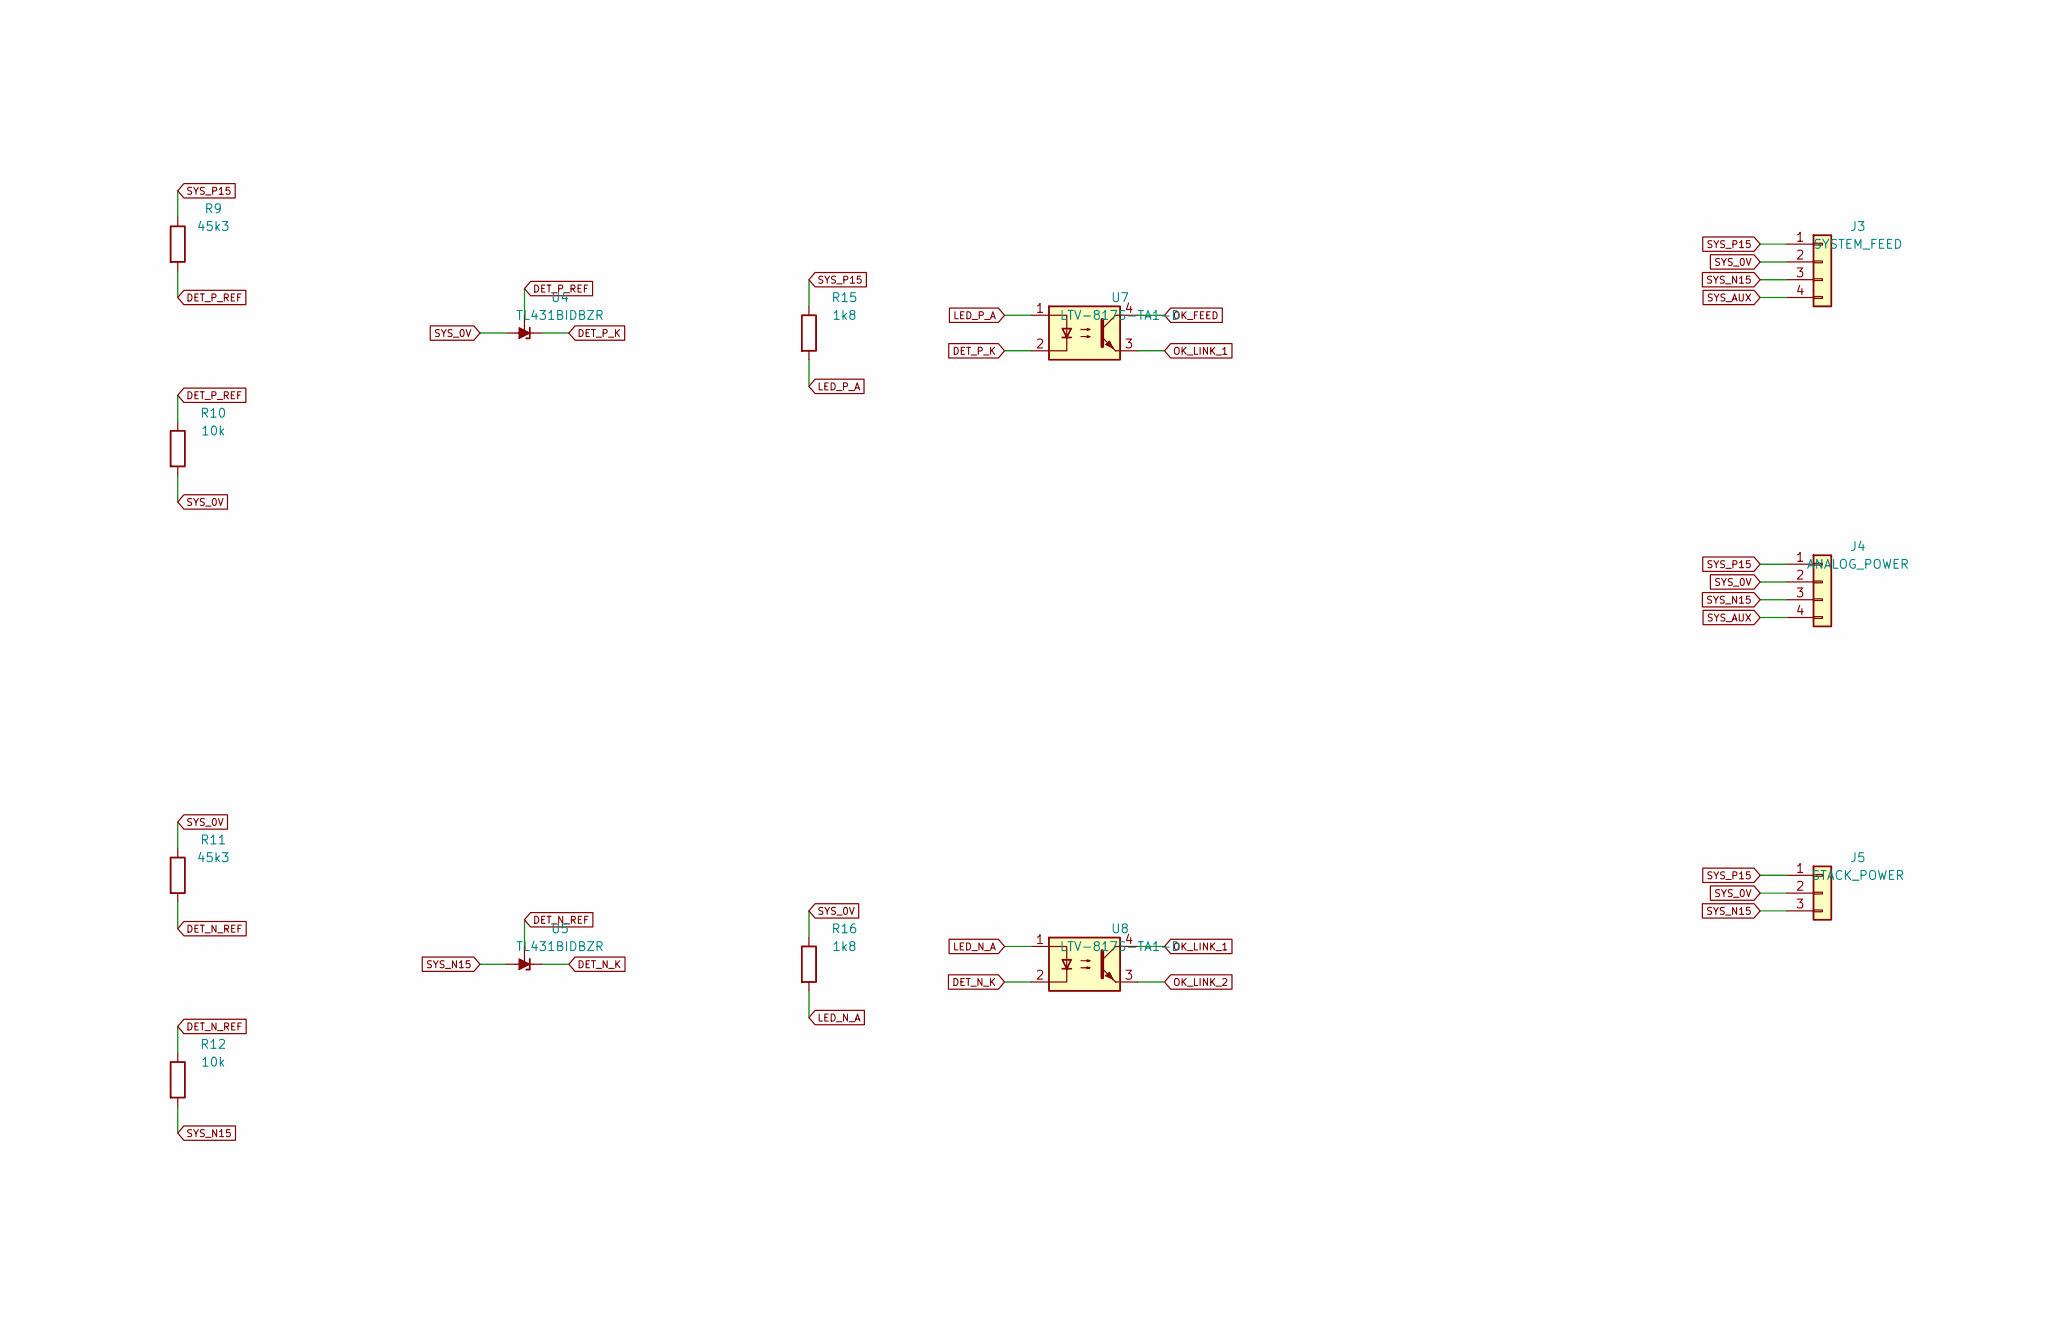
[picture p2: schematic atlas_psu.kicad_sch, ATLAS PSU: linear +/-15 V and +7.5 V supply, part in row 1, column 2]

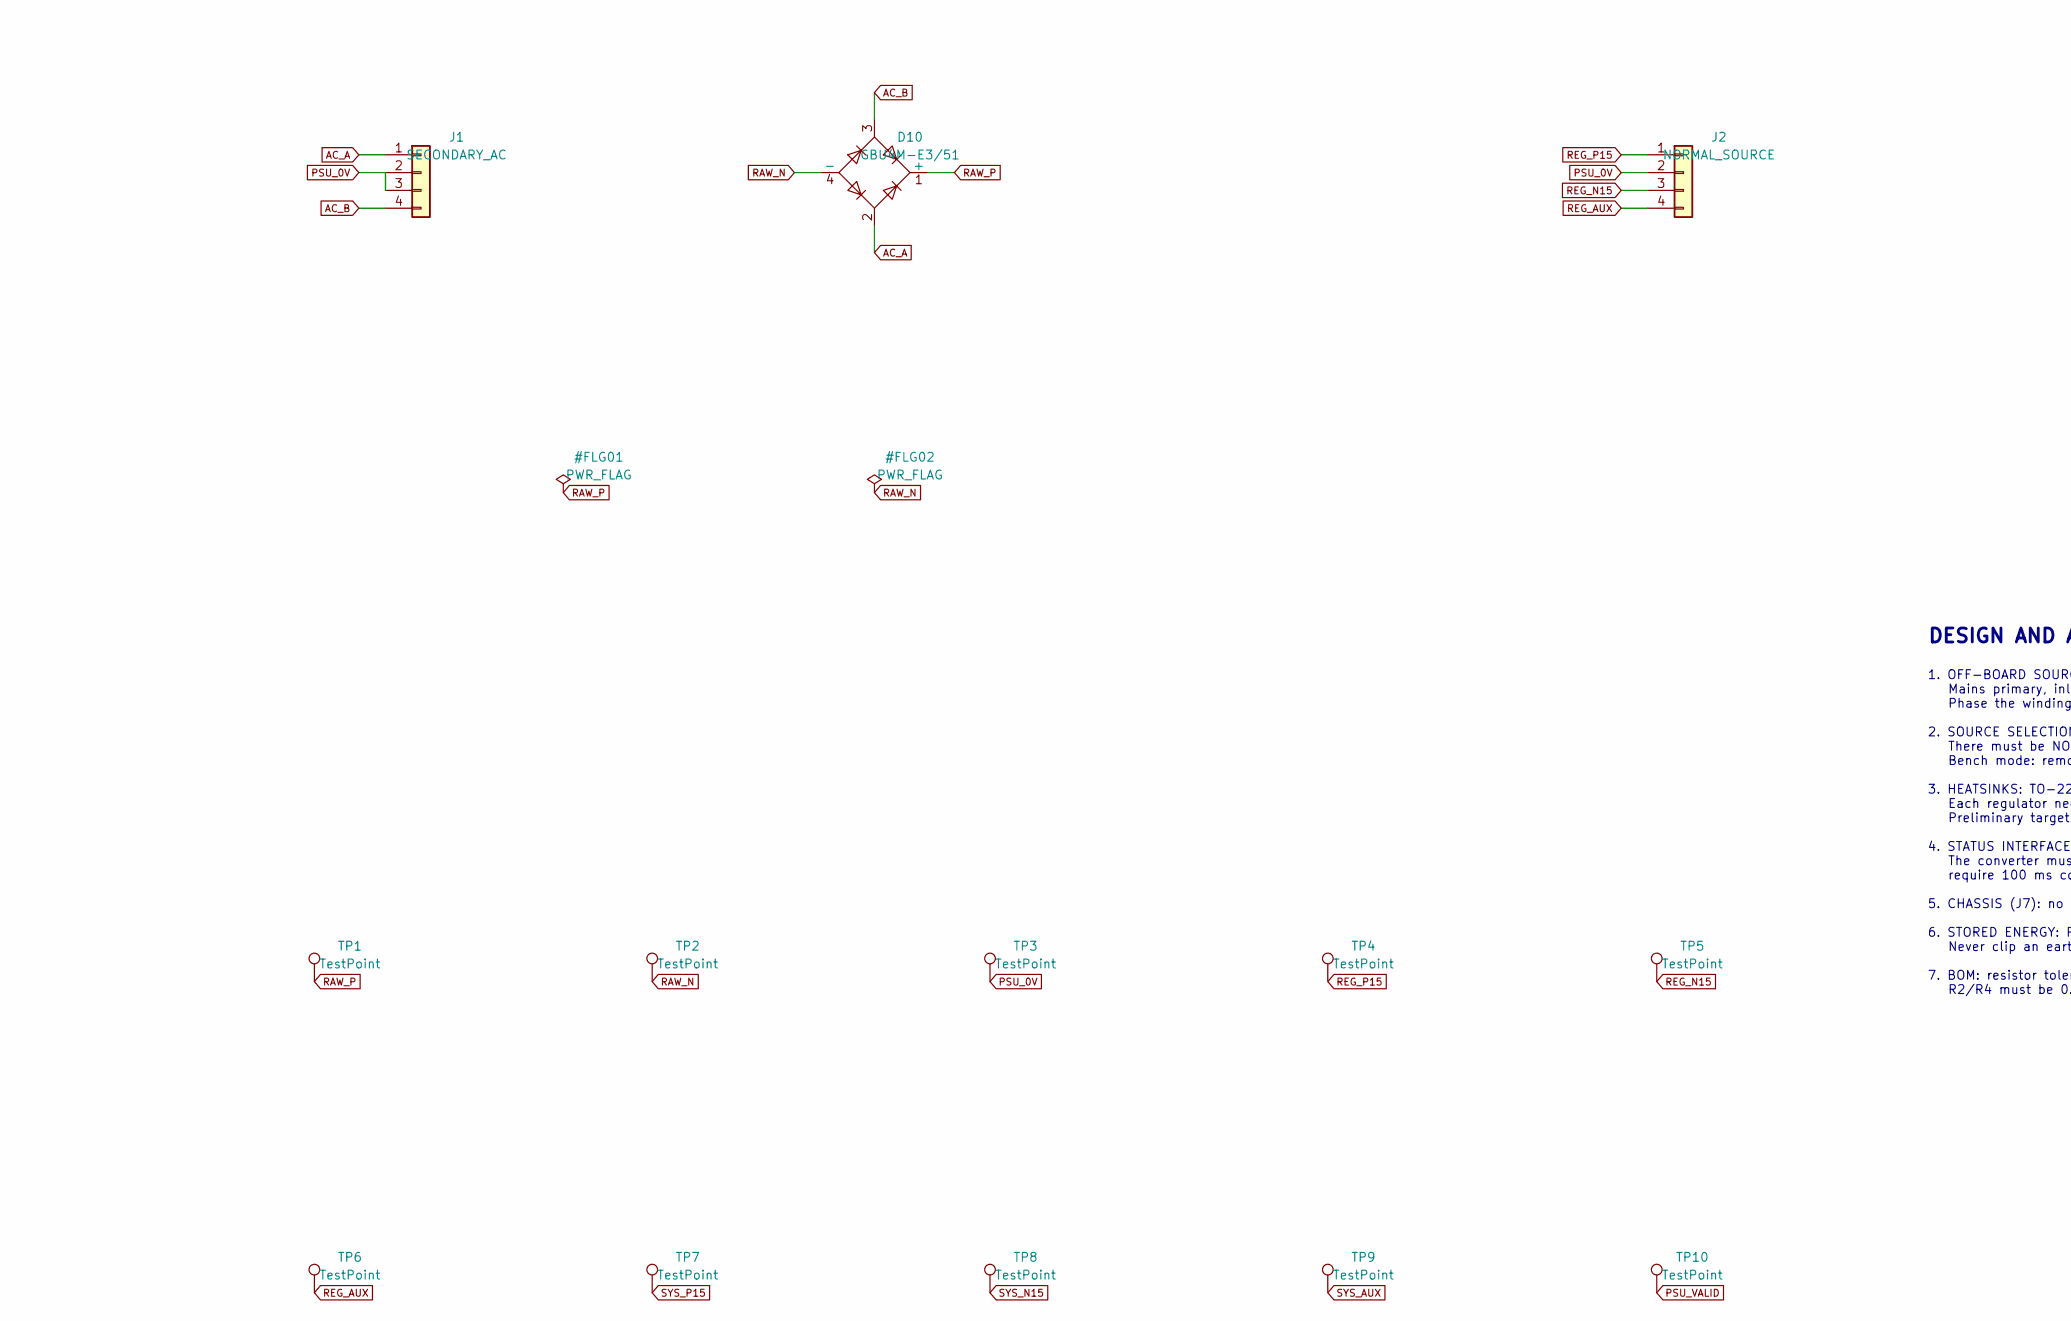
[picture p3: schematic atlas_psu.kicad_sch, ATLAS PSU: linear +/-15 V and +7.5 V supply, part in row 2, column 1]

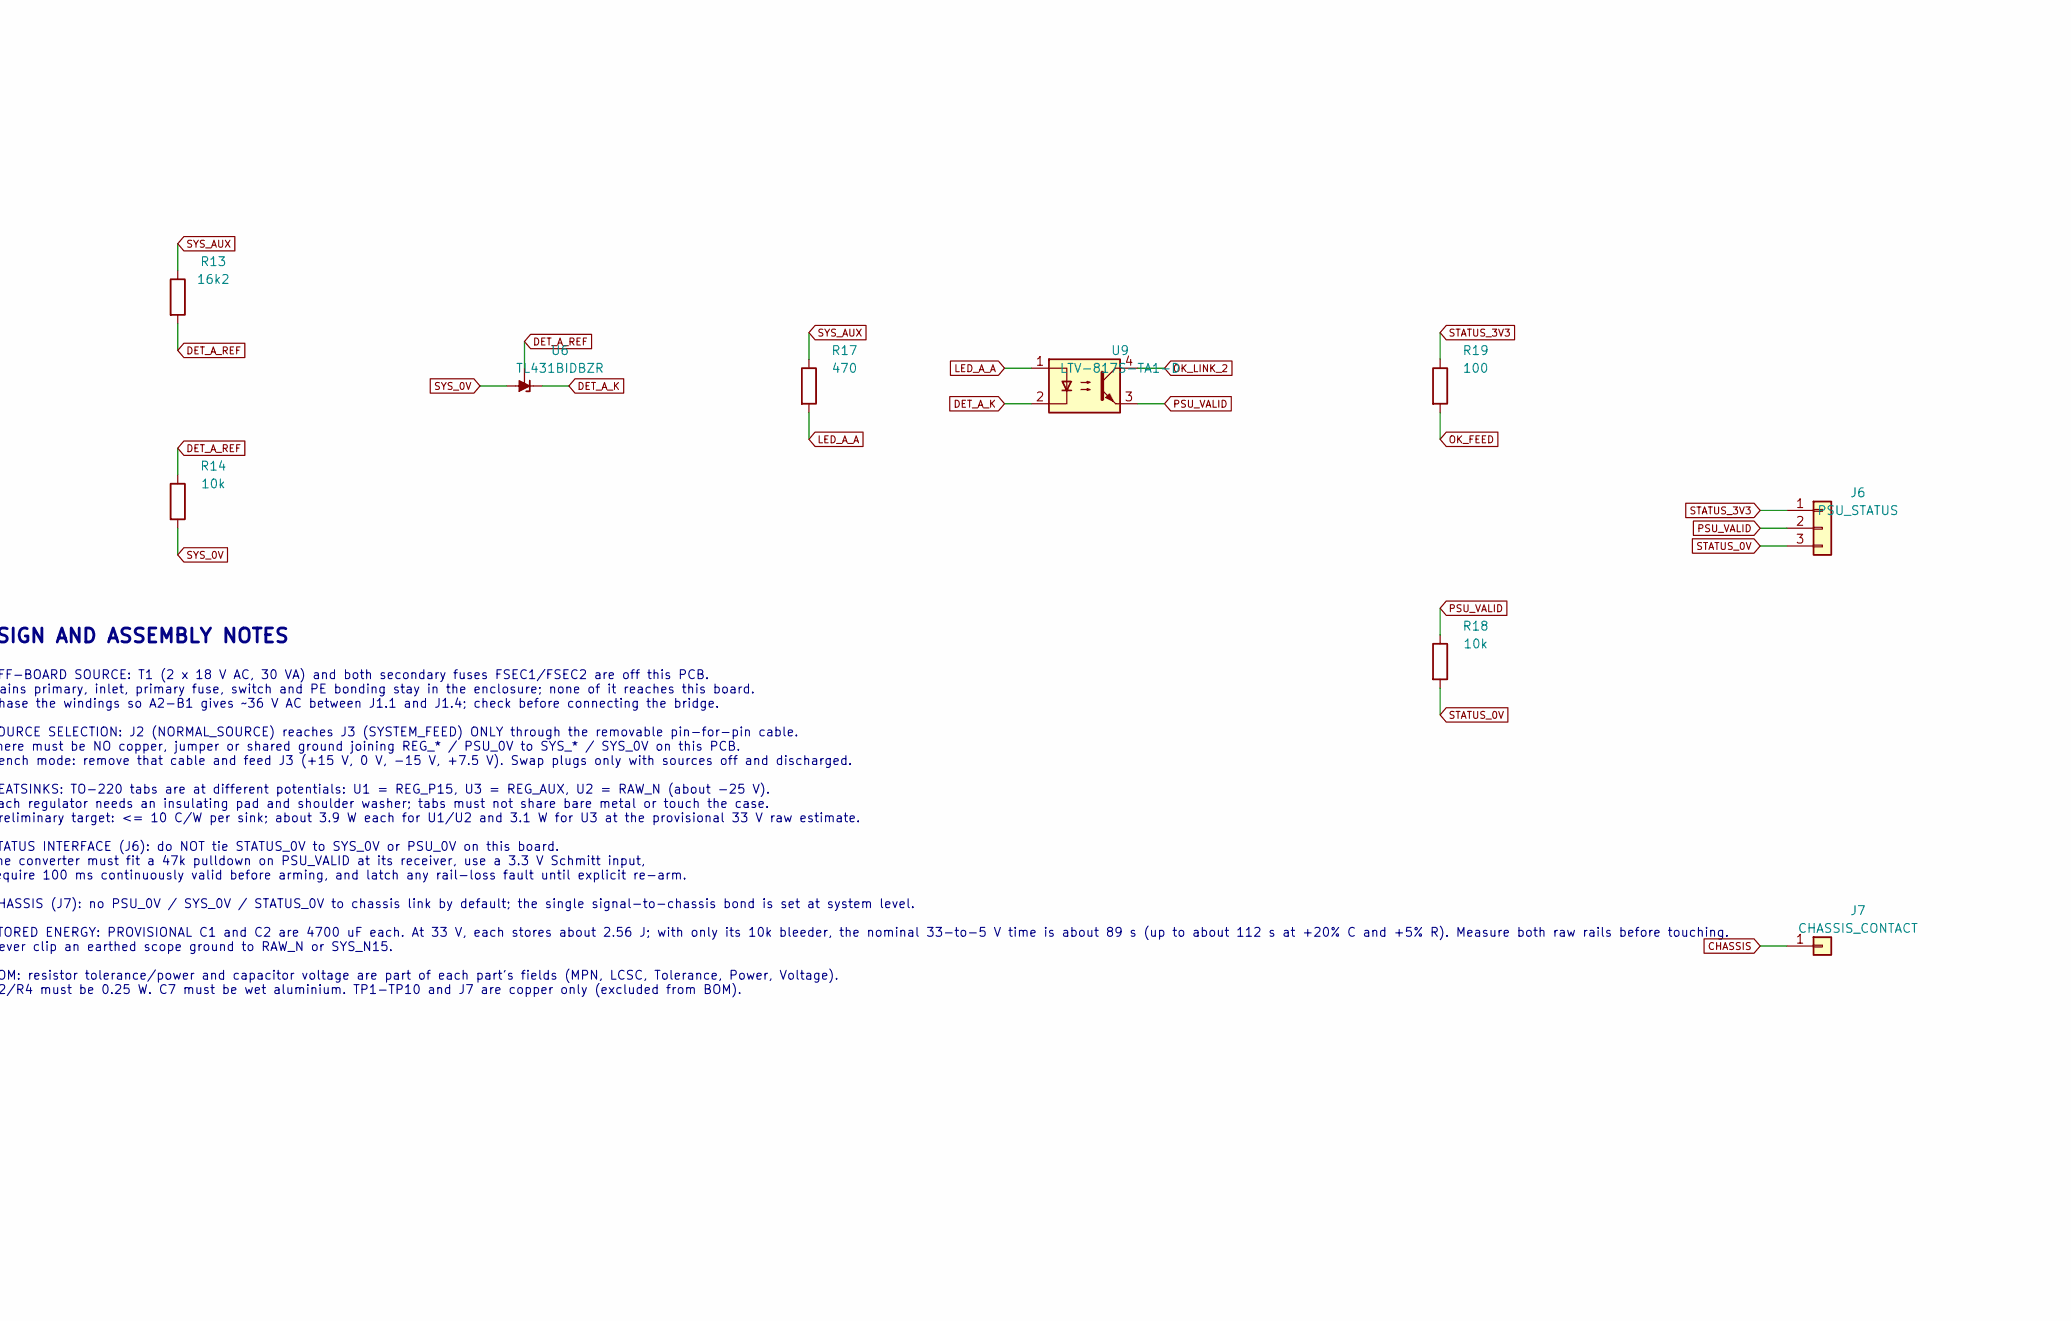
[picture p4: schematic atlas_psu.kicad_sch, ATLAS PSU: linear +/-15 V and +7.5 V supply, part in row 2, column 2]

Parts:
C1, C2: 4700uF; CP_Radial_D30.0mm_P10.00mm_SnapIn; Tolerance 20%; Voltage 50V; MPN LGY1H472MELB30; LCSC C1582310
C3, C5, C12, C13: 100nF; C_0603_1608Metric; Tolerance 10%; Voltage 50V; MPN CL10B104KB8NNNC; LCSC C1591
C4, C6, C8, C9, C10, C11: 10uF; CP_Elec_6.3x5.4_Nichicon; Tolerance 20%; Voltage 50V; MPN UWT1H100MCL1GB; LCSC C445064
C7: 47uF; CP_Elec_6.3x7.7; Tolerance 20%; Voltage 50V; MPN UWT1H470MCL1GS; LCSC C445060
D1, D2, D3, D4, D5, D6, D7, D8, D9: M7; D_SMA; MPN M7; LCSC C95872
D10: GBU4M-E3/51; Diode_Bridge_Vishay_GBU; MPN GBU4M-E3/51; LCSC C3008977
J1: SECONDARY_AC; TerminalBlock_Phoenix_MKDS-1,5-4-5.08_1x04_P5.08mm_Horizont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; MPN MKDS 1,5/4-5,08
J2: NORMAL_SOURCE; JST_XH_B4B-XH-A_1x04_P2.50mm_Vertical; MPN B4B-XH-A; LCSC C41422491
J3: SYSTEM_FEED; JST_XH_B4B-XH-A_1x04_P2.50mm_Vertical; MPN B4B-XH-A; LCSC C41422491
J4: ANALOG_POWER; JST_XH_B4B-XH-A_1x04_P2.50mm_Vertical; MPN B4B-XH-A; LCSC C41422491
J5: STACK_POWER; JST_XH_B3B-XH-A_1x03_P2.50mm_Vertical; MPN B3B-XH-A(LF)(SN); LCSC C144394
J6: PSU_STATUS; JST_GH_SM03B-GHS-TB_1x03-1MP_P1.25mm_Horizontal; MPN SM03B-GHS-TB(LF)(SN); LCSC C514175
J7: CHASSIS_CONTACT; SolderWirePad_1x01_SMD_1.5x3mm
R1, R3, R5: 110; R_0603_1608Metric; Tolerance 0.1%; MPN RN73R1JTTD1100B25; LCSC C2508454
R2, R4: 1k21; R_0805_2012Metric; Tolerance 0.1%; MPN ERA-6VEB1211V; LCSC C3986344
R6: 549; R_0805_2012Metric; Tolerance 0.1%; MPN ERA-6AEB5490V; LCSC C2087831
R7, R8: 10k; R_2010_5025Metric; Tolerance 5%; MPN 2010W2J0103T4S; LCSC C20349
R9, R11: 45k3; R_0603_1608Metric; Tolerance 0.1%; MPN ERA-3AEB4532V; LCSC C3951453
R10, R12, R14, R18: 10k; R_0603_1608Metric; Tolerance 1%; MPN 0603WAF1002T5E; LCSC C25804
R13: 16k2; R_0603_1608Metric; Tolerance 1%; MPN RTT031622FTP; LCSC C103329
R15, R16: 1k8; R_1206_3216Metric; Tolerance 1%; MPN CRCW12061K80FKEBC; LCSC C4211031
R17: 470; R_1206_3216Metric; Tolerance 1%; MPN CR1206F44700G; LCSC C102199
R19: 100; R_0603_1608Metric; Tolerance 1%; MPN 0603WAF1000T5E; LCSC C22775
TP1, TP2, TP3, TP4, TP5, TP6, TP7, TP8, TP9, TP10: TestPoint; TestPoint_Pad_D1.0mm
U1, U3: LM317T; TO-220-3_Vertical; MPN LM317T; LCSC C39583120
U2: LM337T; TO-220-3_Vertical; MPN LM337T; LCSC C5345
U4, U5, U6: TL431BIDBZR; SOT-23; MPN TL431BIDBZR; LCSC C41283
U7, U8, U9: LTV-817S-TA1-D; SMDIP-4_W9.53mm; MPN LTV-817S-TA1-D; LCSC C114603

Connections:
AC_A: D10.2, J1.1
AC_B: D10.3, J1.4
ADJ_AUX: C11.1, D6.2 (A), R5.2, R6.1, U3.1 (ADJ)
ADJ_N: C10.2, D4.1 (K), R3.2, R4.1, U2.1 (ADJ)
ADJ_P: C9.1, D2.2 (A), R1.2, R2.1, U1.1 (ADJ)
CHASSIS: J7.1 (Pin_1_1)
DET_A_K: U6.1 (K), U9.2
DET_A_REF: R13.2, R14.1, U6.2 (REF)
DET_N_K: U5.1 (K), U8.2
DET_N_REF: R11.2, R12.1, U5.2 (REF)
DET_P_K: U4.1 (K), U7.2
DET_P_REF: R9.2, R10.1, U4.2 (REF)
LED_A_A: R17.2, U9.1
LED_N_A: R16.2, U8.1
LED_P_A: R15.2, U7.1
OK_FEED: R19.2, U7.4
OK_LINK_1: U7.3, U8.4
OK_LINK_2: U8.3, U9.4
PSU_0V: C1.2, C2.1, C3.2, C4.1, C5.2, C6.2, C7.1, C8.2, C9.2, C10.1, C11.2, C12.2, C13.2, D7.2 (A), D8.1 (K), D9.2 (A), J1.2, J1.3, J2.2, R2.2, R4.2, R6.2, R7.2, R8.1, TP3.1 (1_1)
PSU_VALID: J6.2, R18.1, TP10.1 (1_1), U9.3
RAW_N: C2.2, C4.2, D3.2 (A), D10.4 (-), R8.2, TP2.1 (1_1), U2.2 (VI)
RAW_P: C1.1, C3.1, C5.1, D1.1 (K), D5.1 (K), D10.1 (+), R7.1, TP1.1 (1_1), U1.3 (VI), U3.3 (VI)
REG_AUX: C8.1, C13.1, D5.2 (A), D6.1 (K), D9.1 (K), J2.4, R5.1, TP6.1 (1_1), U3.2 (VO)
REG_N15: C7.2, D3.1 (K), D4.2 (A), D8.2 (A), J2.3, R3.1, TP5.1 (1_1), U2.3 (VO)
REG_P15: C6.1, C12.1, D1.2 (A), D2.1 (K), D7.1 (K), J2.1, R1.1, TP4.1 (1_1), U1.2 (VO)
STATUS_0V: J6.3, R18.2
STATUS_3V3: J6.1, R19.1
SYS_0V: J3.2, J4.2, J5.2, R10.2, R11.1, R14.2, R16.1, U4.3 (A), U6.3 (A)
SYS_AUX: J3.4, J4.4, R13.1, R17.1, TP9.1 (1_1)
SYS_N15: J3.3, J4.3, J5.3, R12.2, TP8.1 (1_1), U5.3 (A)
SYS_P15: J3.1, J4.1, J5.1, R9.1, R15.1, TP7.1 (1_1)

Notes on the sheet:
DESIGN AND ASSEMBLY NOTES
1. OFF-BOARD SOURCE: T1 (2 x 18 V AC, 30 VA) and both secondary fuses FSEC1/FSEC2 are off this PCB. Mains primary, inlet, primary fuse, switch and PE bonding stay in the enclosure; none of it reaches this board. Phase the windings so A2-B1 gives ~36 V AC between J1.1 and J1.4; check before connecti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

Board: 2 copper layers, 68 parts (0 on the bottom side), 30 nets, no tracks yet.

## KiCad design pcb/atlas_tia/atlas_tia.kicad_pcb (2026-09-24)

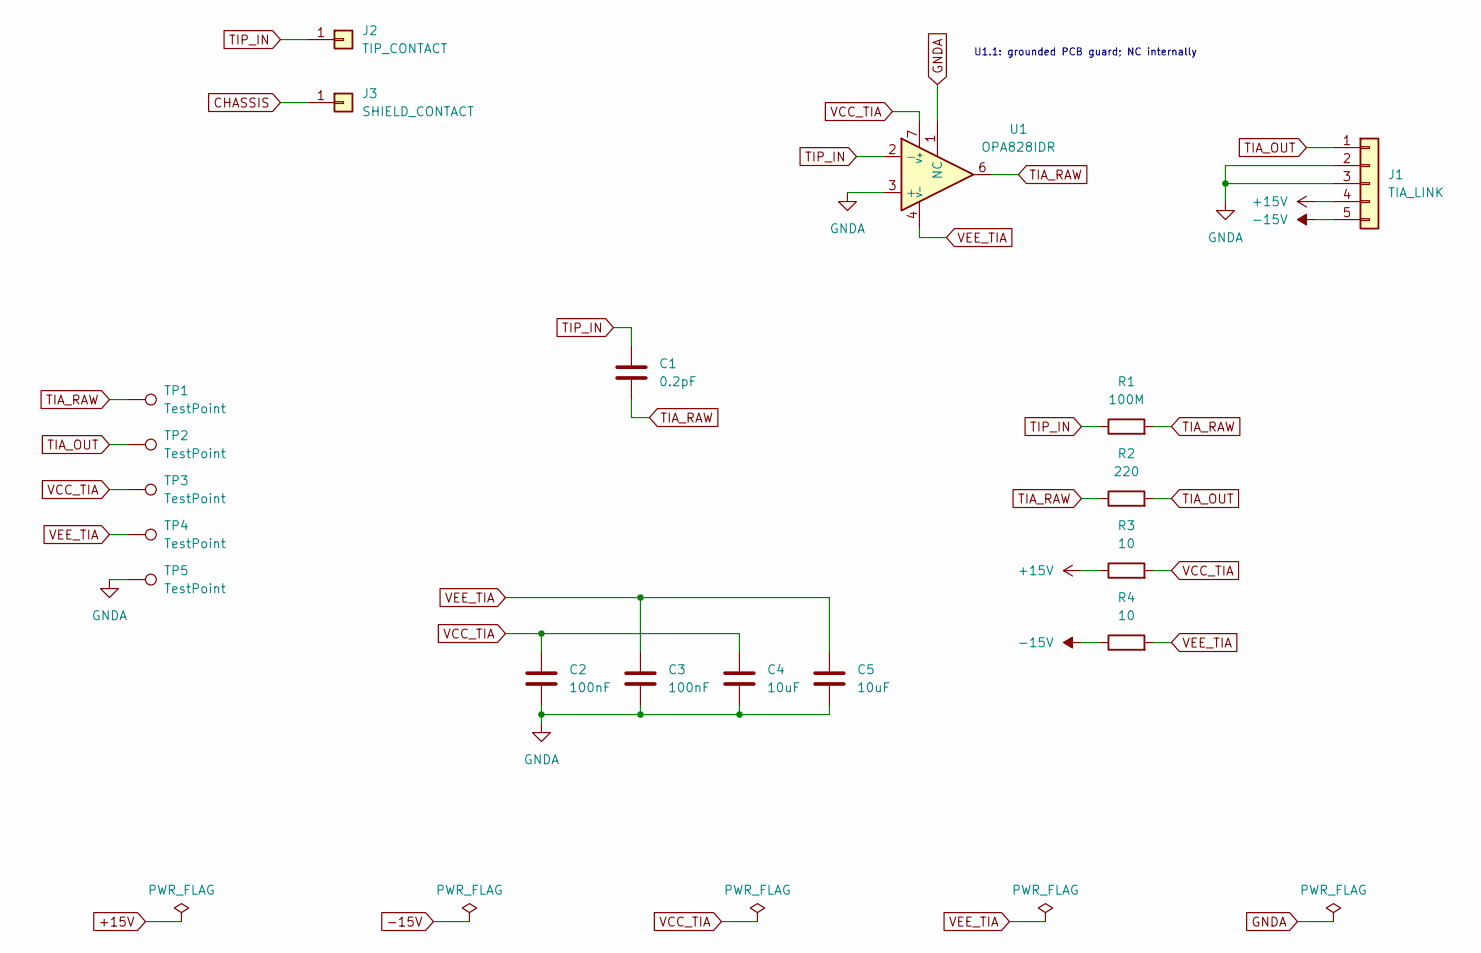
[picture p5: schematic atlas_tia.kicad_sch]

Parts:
C1: 0.2pF; C_0603_1608Metric_Guard; Voltage 50V; Tolerance ±0.1pF; MPN CQ0603BRNPO9BNR20
C2, C3: 100nF; C_0603_1608Metric; Voltage 50V
C4, C5: 10uF; C_1210_3225Metric; Voltage 50V
J1: TIA_LINK; JST_GH_SM05B-GHS-TB_1x05-1MP_P1.25mm_Horizontal; MPN SM05B-GHS-TB
J2: TIP_CONTACT; SolderWirePad_1x01_SMD_1x2mm
J3: SHIELD_CONTACT; SolderWirePad_1x01_SMD_1.5x3mm
R1: 100M; R_1206_3216Metric_Guard; Tolerance 1%
R2: 220; R_0603_1608Metric; Tolerance 1%
R3, R4: 10; R_0603_1608Metric; Tolerance 1%
TP1, TP2, TP3, TP4, TP5: TestPoint; TestPoint_Pad_D1.0mm
U1: OPA828IDR; SOIC-8_3.9x4.9mm_P1.27mm_Guard

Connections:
+15V: J1.4, R3.1
-15V: J1.5, R4.1
CHASSIS: J3.1 (Pin_1_1)
GNDA: C2.2, C3.2, C4.2, C5.2, J1.2, J1.3, TP5.1 (1_1), U1.1 (NC), U1.3 (+)
TIA_OUT: J1.1, R2.2, TP2.1 (1_1)
TIA_RAW: C1.2, R1.2, R2.1, TP1.1 (1_1), U1.6
TIP_IN: C1.1, J2.1 (Pin_1_1), R1.1, U1.2 (-)
VCC_TIA: C2.1, C4.1, R3.2, TP3.1 (1_1), U1.7 (V+)
VEE_TIA: C3.1, C5.1, R4.2, TP4.1 (1_1), U1.4 (V-)

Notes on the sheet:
U1.1: grounded PCB guard; NC internally

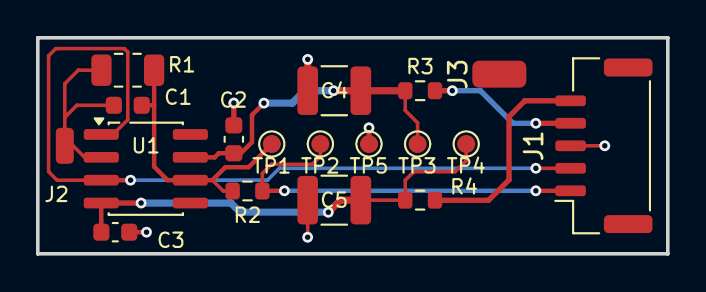
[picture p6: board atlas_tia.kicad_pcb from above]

Board: 2 copper layers, 35.0 x 12.0 mm, 18 parts (0 on the bottom side), 8 nets.

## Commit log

2026-09-07 switched names in README to ATLAS
2026-09-07 Update README to simplify file structure section
    Removed detailed file structure for PCB components.
2026-09-07 Add BOM
2026-09-09 last commit before save
    [atlas_tia.kicad_pcb, atlas_tia.kicad_sch]
2026-09-10 Ignore local planning documents and add PSU project
    [atlas_psu.kicad_pcb, atlas_psu.kicad_sch]
2026-09-10 finished TIA layout
    [atlas_tia.kicad_pcb, atlas_tia.kicad_sch]
2026-09-10 final save + updated README
    [atlas_tia.kicad_pcb, atlas_tia.kicad_sch]
2026-09-10 edited gitignore; finished TIA layout
    [atlas_tia.kicad_pcb]
2026-09-24 PSU schematic: add BOM fields, design notes and power net class; ignore review docs
    - Add Manufacturer/MPN/LCSC/Tolerance/Power/Voltage fields from the design plan
    - Add title block and design/assembly notes to the PSU sheet
    - Add Power net class for AC, RAW, REG, SYS and PSU_0V nets
    - Import PSU footprints into the board
    - Ignore *_REVIEW.md, *_EVALUATION.md and PCB routing_review snapshots
    [atlas_psu.kicad_pcb, atlas_psu.kicad_sch]
2026-09-24 TIA layout updates, guard footprints and LTspice compensation study
    - Update TIA schematic, board and project
    - Add guard-ring variants of C_0603, R_1206 and SOIC-8 footprints to atlas_parts_lib
    - Add LTspice TIA netlists (proxy and TI OPAx828 model), analysis scripts and sweep results
    [atlas_tia.kicad_pcb, atlas_tia.kicad_sch, compensation_sweep.csv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]
2026-09-29 Reconcile PSU prototype and publish validation studies
    [atlas_psu.kicad_pcb, atlas_psu.kicad_sch, feedback_stray_budget.csv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]
2026-09-29 Track ATLAS plans and consolidate status records
